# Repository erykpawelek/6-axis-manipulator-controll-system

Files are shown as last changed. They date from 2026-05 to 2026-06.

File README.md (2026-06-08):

# Robot for Car Windshield Assembly

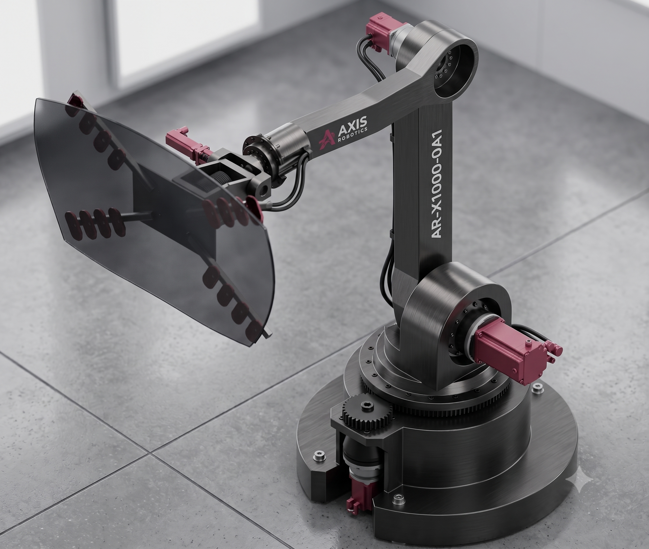
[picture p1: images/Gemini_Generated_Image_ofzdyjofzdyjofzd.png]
Visualization


**Authors:** Eryk Pawełek, Dawid Pietrzyk, Nikodem Weltrowski, Maksymilian Wywiał

## Project Overview

This project details the design, kinematic and dynamic analysis, and control simulation of a 6-Degree of Freedom (DoF) articulated mechatronic manipulator dedicated to the automated assembly of automotive windshields integrated and simulatied fully in MATLAB/Simulink environment using Simscape addition. The system is engineered to handle variable payload capacities (up to approximately 20 kg for the glass alone, plus the mass of a multi-pad vacuum gripping system) while maintaining the high spatial precision required for continuous urethane adhesive application and frame insertion.

A fully articulated structure utilizing 6 rotational joints driven by AC servomotors was selected to maximize maneuverability and minimize the spatial footprint, allowing the end-effector to reach complex car body angles without collision.

## Design Assumptions & Motion Parameters

To ensure safe handling of fragile laminated glass and high positioning accuracy, the motion parameters were bounded below the absolute maximum capabilities of standard industrial robots. The operation is divided into two distinct phases:

- **Transfer Phase:** Fast transit from the picking station to the vehicle workspace. Maximum Tool Center Point (TCP) velocity is set to $1.0m/s$ with an acceleration of $2.0m/s^{2}$.
- **Mounting Phase:** Precision alignment and insertion. Maximum TCP velocity is reduced to $0.25m/s$ with an acceleration of $0.5m/s^{2}$

## Kinematic Analysis

### Denavit-Hartenberg Parameters

The spatial geometry of the manipulator is defined using the standard Denavit-Hartenberg (DH) convention.

| $i$ | $\theta_{i}$ | $d_{i}$ | $a_{i}$ | $\alpha_{i}$ | $Range of Motion$ |
| :-: | :---: | :-----: | :-----: | :---: | :---: |
|  1  | $\theta_{1}$ | $d_{1}$ | $0$ | $-\frac{\pi}{2}$ | $\pm180^{\circ}$ |
|  2  | $\theta_{2}-\frac{\pi}{2}$ | $0$ | $a_{2}$ | $0$ | $\pm60^{\circ}$ |
|  3  | $\theta_{3}$ | $0$ | $0$ | $-\frac{\pi}{2}$ | $+60^{\circ} / -240^{\circ}$ |
|  4  | $\theta_{4}$ | $d_{4}$ | $0$ | $\frac{\pi}{2}$  | $\pm180^{\circ}$ |
|  5  | $\theta_{5}$ | $0$ | $0$ | $-\frac{\pi}{2}$ | $\pm90^{\circ}$ |
|  6  | $\theta_{6}$ | $d_{6}$ | $0$ | $0$ | $\pm180^{\circ}$ |

> (Note: $d_{1}=200mm$, $a_{2}=1300mm$, $d_{4}=1200mm$, $d_{6}=400mm$)

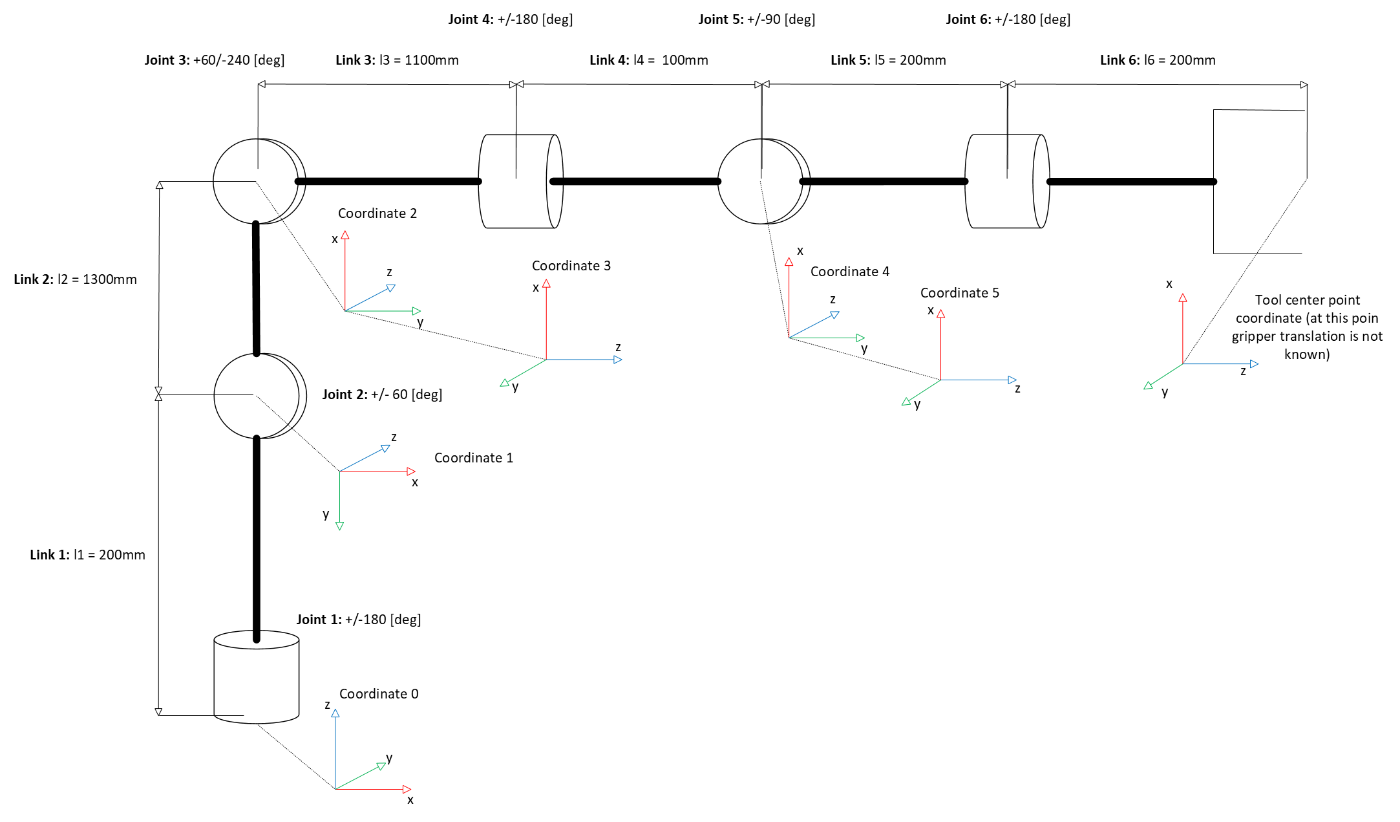
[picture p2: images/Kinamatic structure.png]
Kinematic structure


## Inverse kinematics

The inverse kinematics problem was solved analytically using the kinematic decoupling method, which is applicable because the three consecutive wrist axes (J4, J5, J6) intersect at a single mathematical point.

The position of the wrist center $\overline{P_{a}}$ is isolated from the Tool Center Point (TCP) $\overline{P}$ and the end-effector translation $\overline{P_{w}}$:

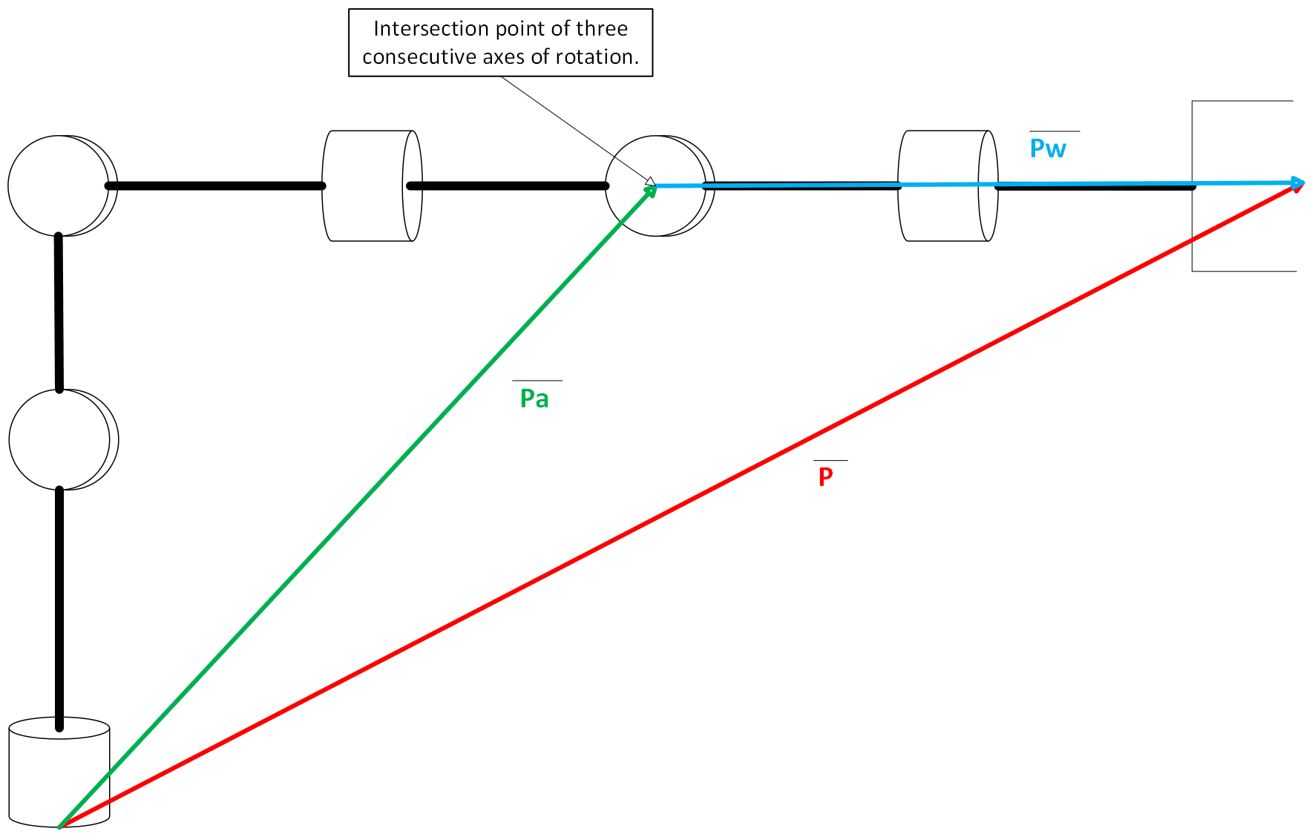
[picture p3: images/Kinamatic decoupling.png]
Kinematic decoupling


## $$\overline{P_{a}} = \overline{P} - \overline{P_{w}}$$

Solving for the base and arm joints ($\theta_{1}$, $\theta_{2}$, $\theta_{3}$), the base rotation is derived as:

### Joint 1 ($\theta_1$):

**$\theta_{1}=atan2(-P_{ay},-P_{ax})$**

or

**$\theta_{1}=atan2(P_{ay},P_{ax})$**

### Joint 3 ($\theta_3$):

First, the intermediate variable $D$ is calculated:

**$D=\frac{a_{2}^{2}+d_{4}^{2}-(P_{ax}^{2}+P_{ay}^{2})-(P_{az}-d_{1})^{2}}{2\cdot a_{2}\cdot d_{4}}$**

Then, $\theta_3$ is extracted using the $atan2$ function:

**$\theta_{3}=atan2(D,\pm\sqrt{1-D^{2}})$**

### Joint 2 ($\theta_2$):

Using the calculated $\theta_3$, constants $M$ and $N$ are defined:

**$M=a_{2}-d_{4}\cdot sin(\theta_{3})$**

**$N=d_{4}\cdot cos(\theta_{3})$**

The solution for $\theta_2$ is:

**$\theta_{2}=atan2(M\cdot R-N\cdot(P_{ax}-d_{1}),N\cdot R+M\cdot(P_{ax}-d_{1}))$**

### Joint 5 ($\theta_5$):

**$\theta_{5}=atan2(\pm\sqrt{R_{13}^{2}+R_{23}^{2}},R_{33})$**

### Joint 4 ($\theta_4$):

The solution depends on the variant of the $sin(\theta_5)$ solution.

For $sin(\theta_5)>0$:

**$\theta_{4}=atan2(-R_{23},-R_{13})$**

For $sin(\theta_5)<0$:

$\theta_{4}=atan2(R_{23},R_{13})$

### Joint 6 ($\theta_6$):

The solution follows the logic for the chosen root of $\theta_5$.

For the positive root of $\theta_5$:

$\theta_{6}=atan2(-R_{32},R_{31})$

For the negative root of $\theta_5$:

$\theta_{6}=atan2(R_{32},-R_{31})$

## Singularity Analysis

Four primary kinematic singularities were identified and mapped within the workspace:

1. **Shoulder Singularity:** Occurs when the wrist center lies exactly on the vertical $z_{0}$ axis ($P_{ax}=0, P_{ay}=0$), resulting in infinite solutions for $\theta_{1}$.

2. **Workspace Boundary:** Occurs when the target exceeds the maximum reach, yielding imaginary roots for $\theta_{3}$.

3. **Elbow Singularity:** Arises when the arm is fully extended or folded ($\theta_{3} = \pm90^{\circ}$), demanding infinite joint velocity for radial extension.

4. **Wrist Singularity:** Occurs when joint 5 is at $0^{\circ}$ or $\pm180^{\circ}$, causing axes 4 and 6 to become coaxial, making their individual angles indeterminate.

## Dynamic Analysis

A dynamic model was developed to calculate the joint torques required for trajectory execution. While the Euler-Lagrange method was initially explored, the analytical derivatives for the rotational kinetic energy of the distal links proved computationally expensive.

The equations of motion are expressed in standard matrix form:

$$\tau = M\dot{q} + C + G$$

> Where $M$ is the inertia matrix, $C$ represents the Coriolis and centrifugal forces, $G$ is the gravity vector, and $\dot{q}$ contains the joint accelerations.

## Simulation & Control (Simscape Multibody)

The CAD geometry, including proper mass and inertia tensors (calculated for steel, $\rho = 7850~kg/m^{3}$), was integrated into MATLAB/Simulink using the Simscape Multibody module.

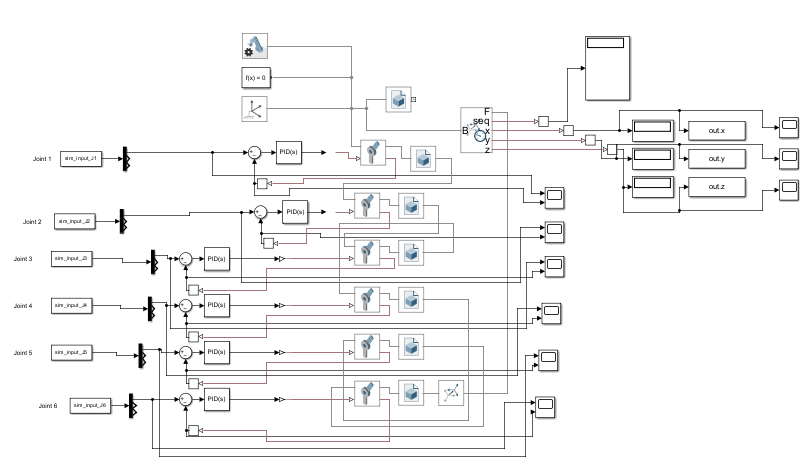
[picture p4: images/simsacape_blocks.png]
Simsacape block diagram


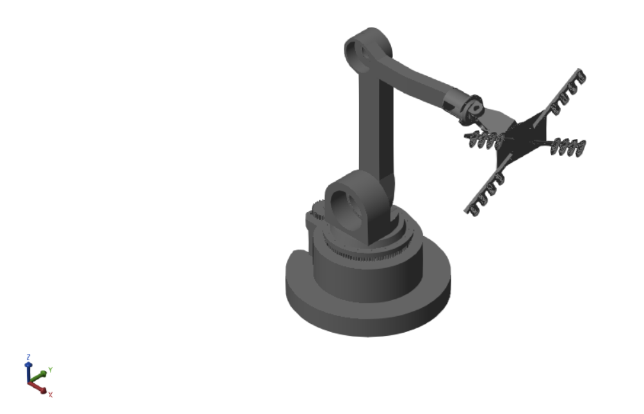
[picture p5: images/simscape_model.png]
Simsacape model


## Trajectory Generation

A 5th-order polynomial interpolation was applied for joint space trajectories to ensure smooth, continuous velocity and acceleration profiles, while trapezoidal generation was utilized for linear motion segments.

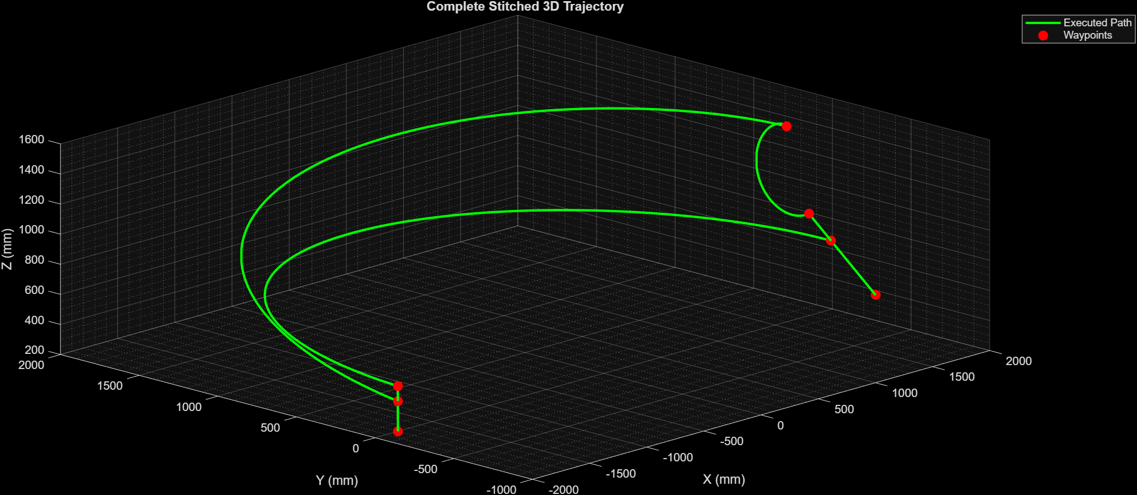
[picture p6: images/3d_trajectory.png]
3D path

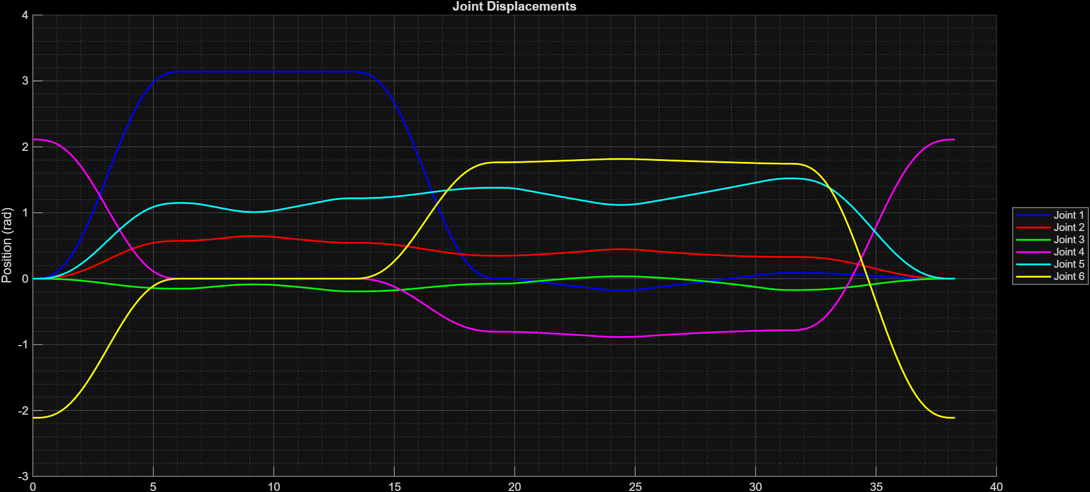
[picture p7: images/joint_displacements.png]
j_dis

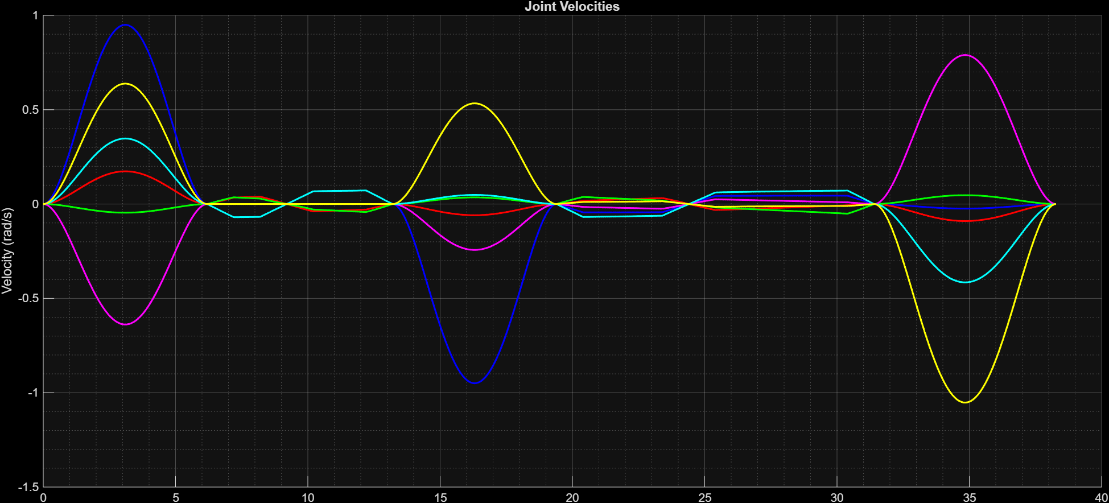
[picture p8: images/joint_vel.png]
j_vel

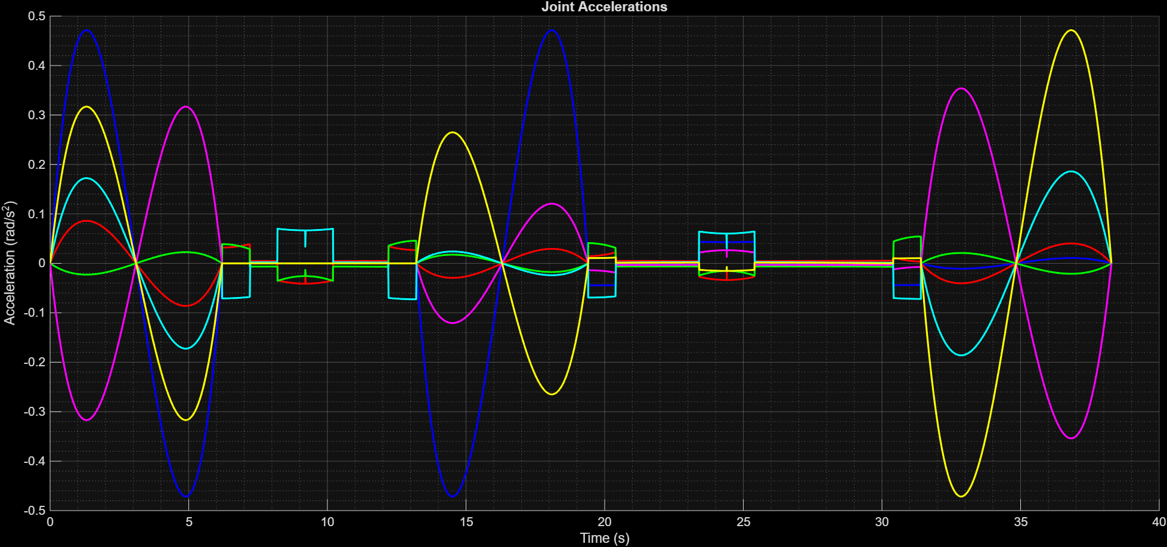
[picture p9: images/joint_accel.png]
j_accel


## PID Control and Error Evaluation

Independent PID controllers were tuned for each joint using a decoupled approach, targeting a settling time of $<0.5s$ and overshoot of $<10\%$.

Tracking evaluation revealed high precision in the joint space (maximum deviations of $\pm0.035rad$ on Joint 1). However, error amplification through the extended kinematic chain (up to $1300mm$ link lengths) resulted in measurable Cartesian deviations at the end-effector.

- X-axis error: Peaked at $\pm44~mm$ during high-speed sweeps.
- Y-axis error: Peaked at $89~mm$ during major joint-space transitions.
- Z-axis error: Oscillated between $5mm$ and $30mm$ during motion.

Analysis indicated that static residual errors at the proximal joints are heavily influenced by the sampling time ($0.001s$), which limits the aggressiveness of the derivative gain before inducing system instability (derivative kick).

## Assembly drawing

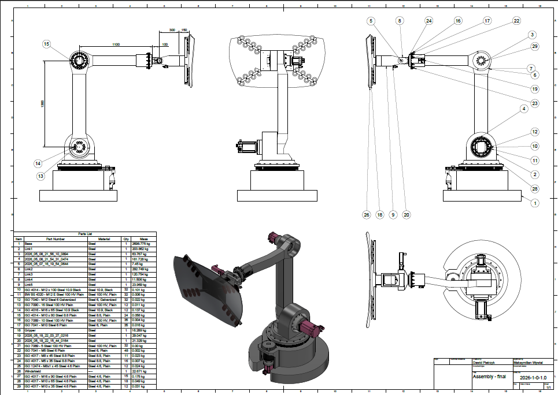
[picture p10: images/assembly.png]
assembly


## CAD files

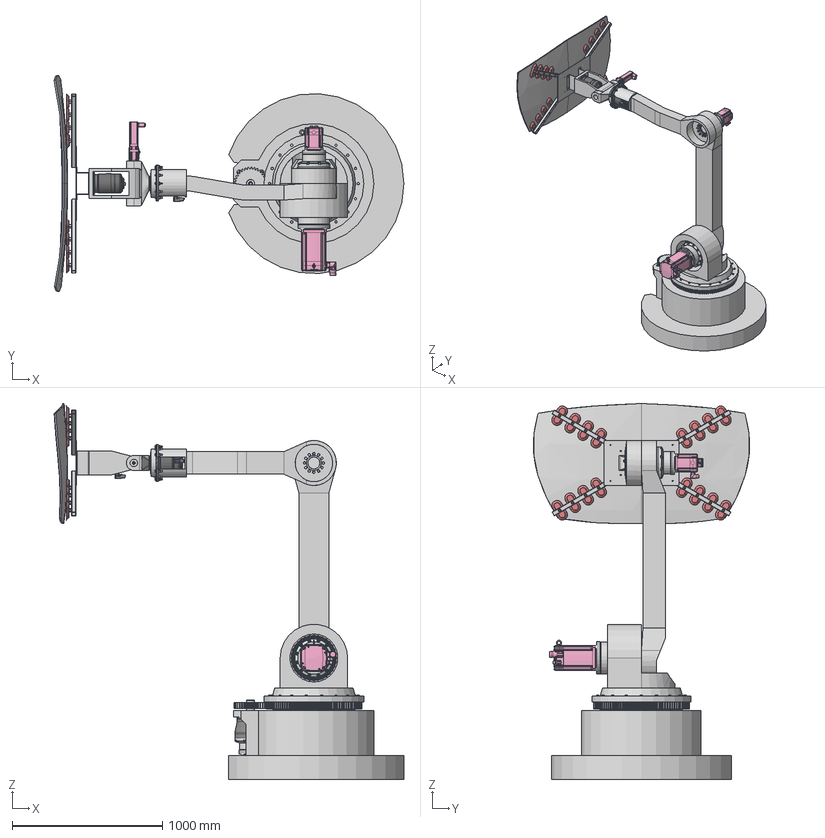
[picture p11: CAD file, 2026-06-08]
simulink/CAD/final/Assembly - final-stp.step
2331.7 x 1441.1 x 2506.2 mm
BALL .750 inch.step_10 x 74
BALL .750 inch.step
BALL .750 inch.step_1
BALL .750 inch.step_2
BALL .750 inch.step_3
BALL .750 inch.step_4
BALL .750 inch.step_5
BALL .750 inch.step_6
BALL .750 inch.step_7
BALL .750 inch.step_8
BALL .750 inch.step_9
HS6-021E002 ASSY.step
HS6-021E003 ASSY.step
HS6021 UPPER SEAL (25382003).step
HS6-021 LOWER SEAL (25382004).step
20069000_20069040.step
Taper Pin_04_1.50.step
ALEMITE 1644-B.step x 2
spinning table
Spur Gear 33 teeth
link1
link2
link4
link5
ISO 4014 - M12 x 100 Steel 10.9 Black x 32
BW BS 4320 - M12 E Steel 100 HV Plain x 32
ISO 7040 - M12 Steel 6 Galvanized x 32
ISO 7090 - 16 Steel 100 HV Plain
ISO 7090 - 16 Steel 100 HV Plain_1
ISO 7090 - 16 Steel 100 HV Plain_2
ISO 7090 - 16 Steel 100 HV Plain_3
ISO 7090 - 16 Steel 100 HV Plain_4
ISO 7090 - 16 Steel 100 HV Plain_5
ISO 7090 - 16 Steel 100 HV Plain_6
ISO 7090 - 16 Steel 100 HV Plain_7
ISO 7090 - 16 Steel 100 HV Plain_8
ISO 7090 - 16 Steel 100 HV Plain_9
ISO 7090 - 16 Steel 100 HV Plain_10
ISO 7090 - 16 Steel 100 HV Plain_11
ISO 4016 - M16 x 65 Steel 10.9 Black
ISO 4016 - M16 x 65 Steel 10.9 Black_1
ISO 4016 - M16 x 65 Steel 10.9 Black_2
ISO 4016 - M16 x 65 Steel 10.9 Black_3
ISO 4016 - M16 x 65 Steel 10.9 Black_4
ISO 4016 - M16 x 65 Steel 10.9 Black_5
ISO 4016 - M16 x 65 Steel 10.9 Black_6
ISO 4016 - M16 x 65 Steel 10.9 Black_7
ISO 4016 - M16 x 65 Steel 10.9 Black_8
ISO 4016 - M16 x 65 Steel 10.9 Black_9
ISO 4016 - M16 x 65 Steel 10.9 Black_10
ISO 4016 - M16 x 65 Steel 10.9 Black_11
ISO 4014 - M10 x 80 Steel 8.8 Plain
ISO 4014 - M10 x 80 Steel 8.8 Plain_1
ISO 4014 - M10 x 80 Steel 8.8 Plain_2
ISO 4014 - M10 x 80 Steel 8.8 Plain_3
ISO 4014 - M10 x 80 Steel 8.8 Plain_4
ISO 4014 - M10 x 80 Steel 8.8 Plain_5
ISO 4014 - M10 x 80 Steel 8.8 Plain_6
ISO 4014 - M10 x 80 Steel 8.8 Plain_7
ISO 4014 - M10 x 80 Steel 8.8 Plain_8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

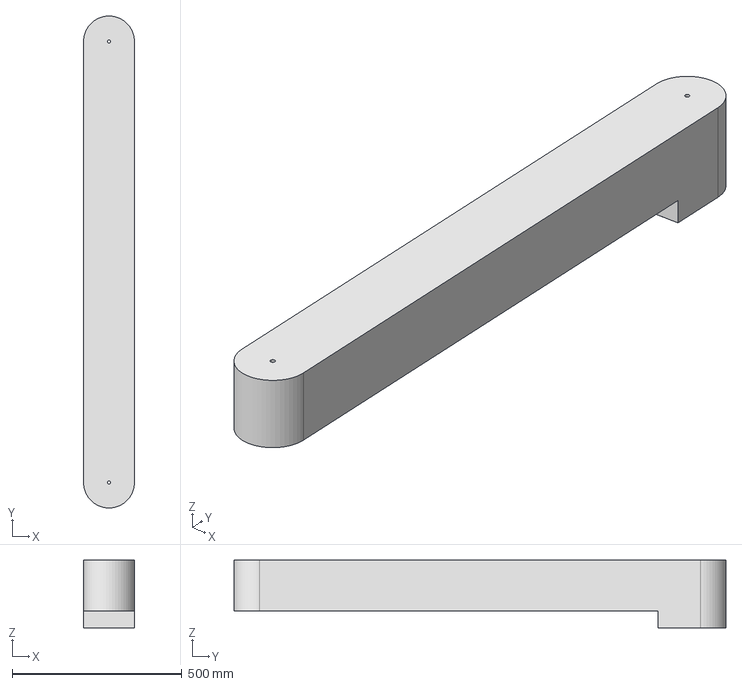
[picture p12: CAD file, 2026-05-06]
simulink/CAD/simplified/step/link2_fixed.stp
150.0 x 1450.0 x 200.0 mm

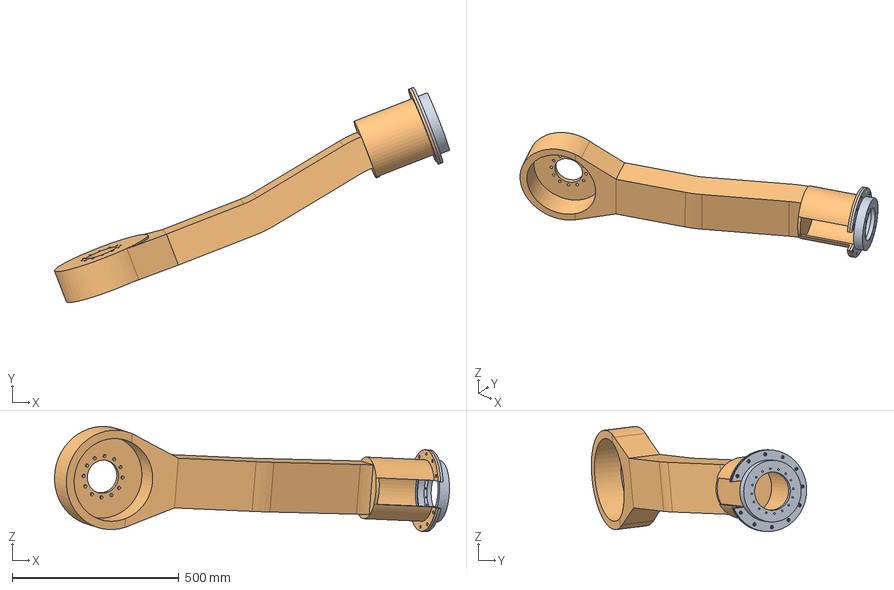
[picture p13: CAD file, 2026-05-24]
simulink/CAD/final/link3-v14.step
1183.7 x 645.2 x 315.1 mm

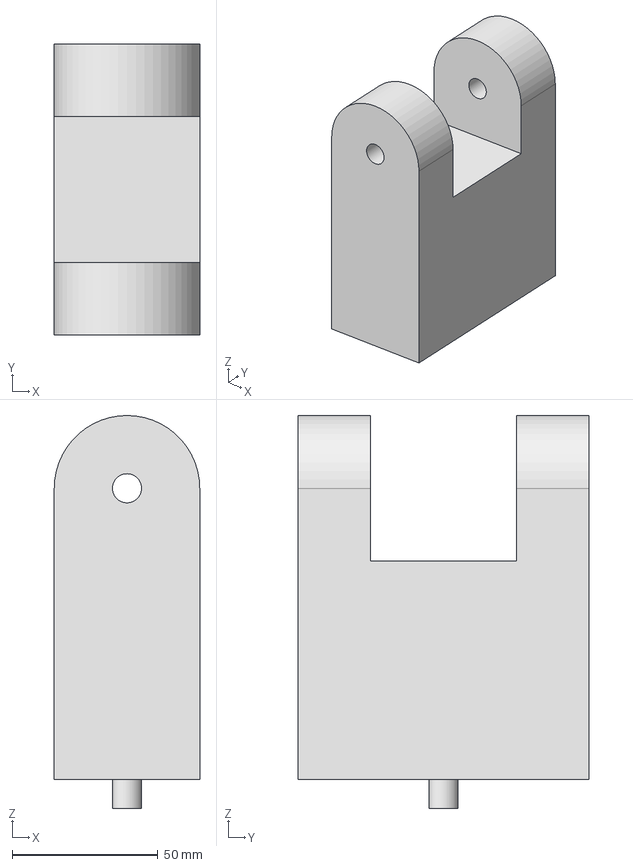
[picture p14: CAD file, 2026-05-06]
simulink/CAD/simplified/step/link4.stp
50.0 x 100.0 x 135.0 mm

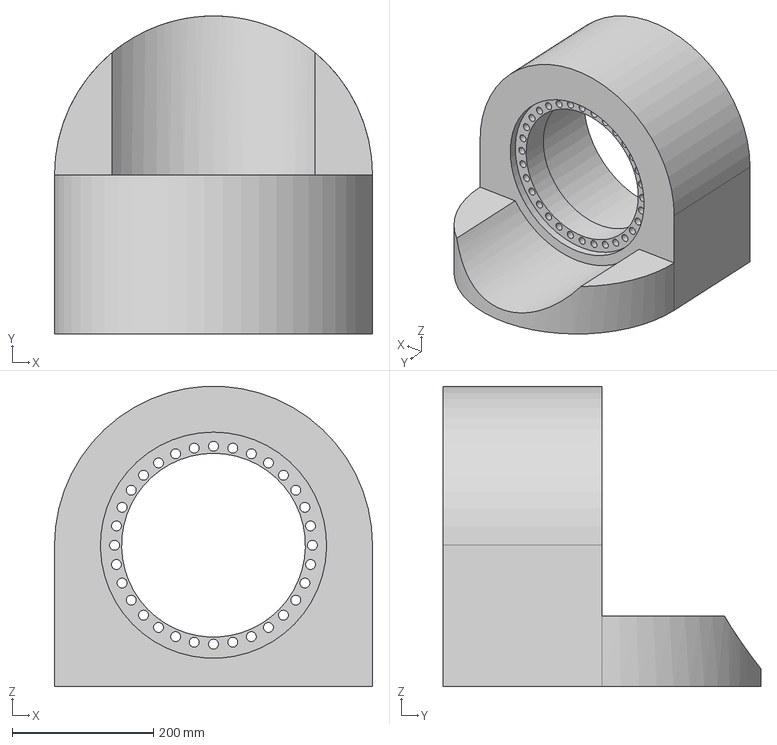
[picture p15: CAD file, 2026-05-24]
simulink/CAD/final/link1-v7.step
450.0 x 450.0 x 424.6 mm

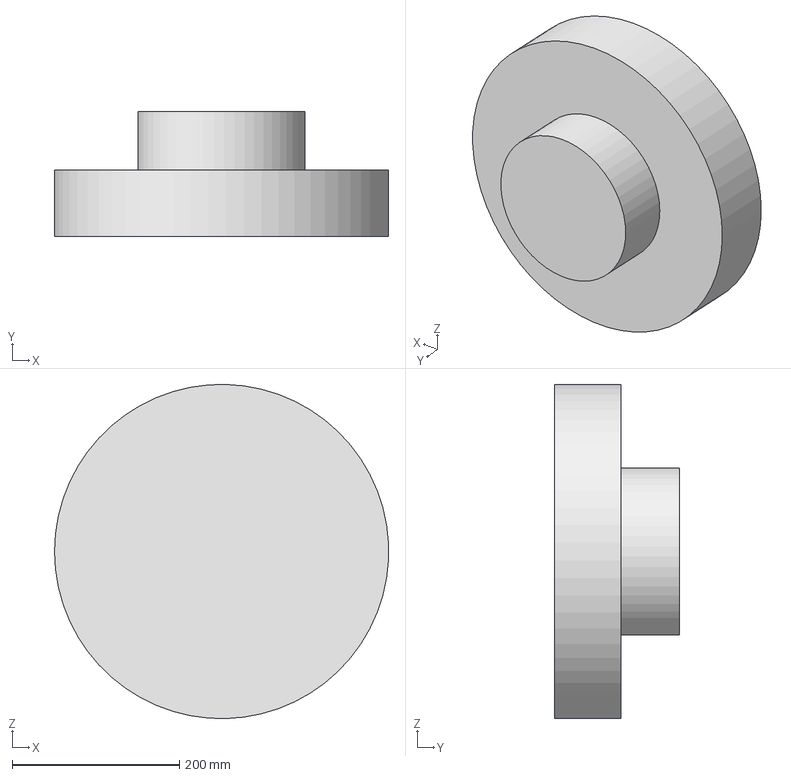
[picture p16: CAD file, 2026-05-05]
simulink/CAD/simplified/step/base.stp
399.7 x 150.0 x 399.9 mm

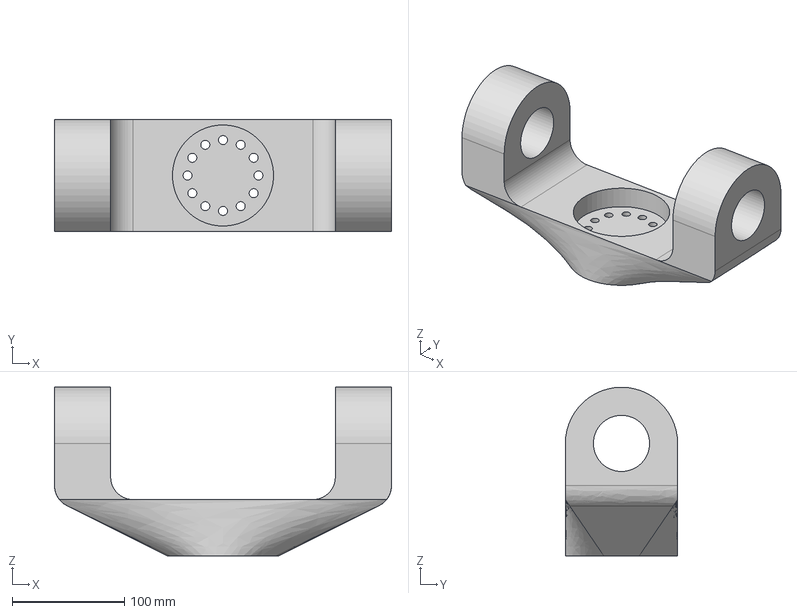
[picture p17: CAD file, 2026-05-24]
simulink/CAD/final/link4-v3.step
300.0 x 100.0 x 150.0 mm

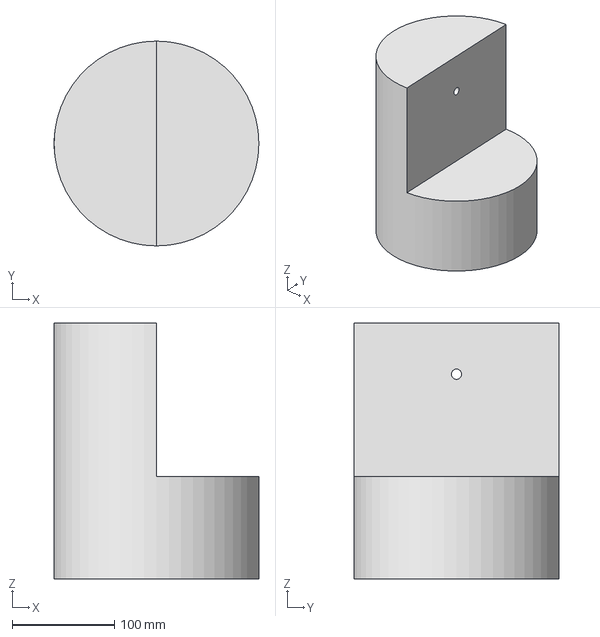
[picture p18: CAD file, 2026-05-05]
simulink/CAD/simplified/step/link1.stp
200.0 x 200.0 x 250.0 mm

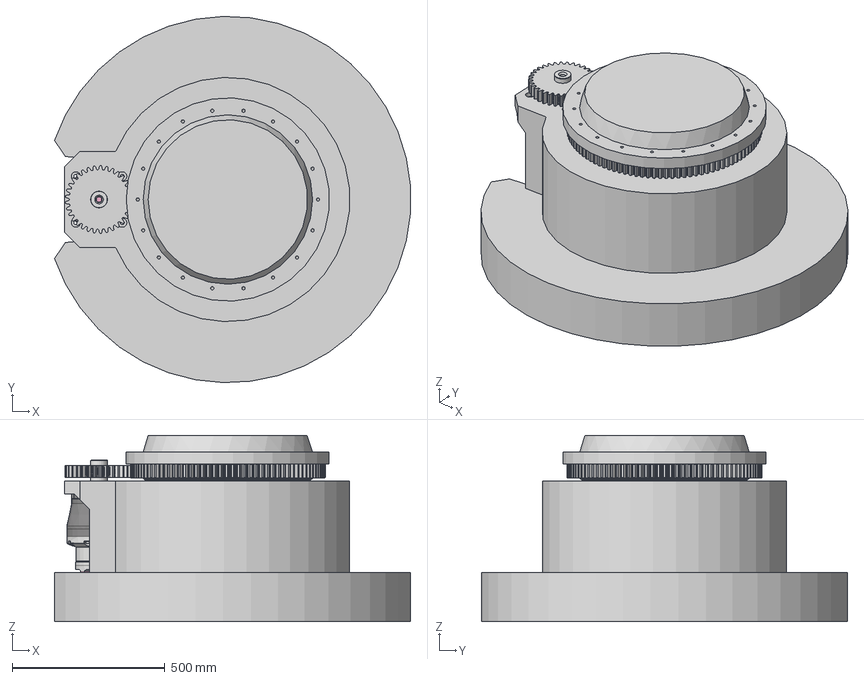
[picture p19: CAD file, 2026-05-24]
simulink/CAD/final/base-v7.step
1166.2 x 1199.6 x 609.9 mm
BALL .750 inch.step_10 x 74
BALL .750 inch.step
BALL .750 inch.step_1
BALL .750 inch.step_2
BALL .750 inch.step_3
BALL .750 inch.step_4
BALL .750 inch.step_5
BALL .750 inch.step_6
BALL .750 inch.step_7
BALL .750 inch.step_8
BALL .750 inch.step_9
HS6-021E002 ASSY.step
HS6-021E003 ASSY.step
HS6021 UPPER SEAL (25382003).step
HS6-021 LOWER SEAL (25382004).step
20069000_20069040.step
Taper Pin_04_1.50.step
ALEMITE 1644-B.step x 2
spinning table
Spur Gear 33 teeth

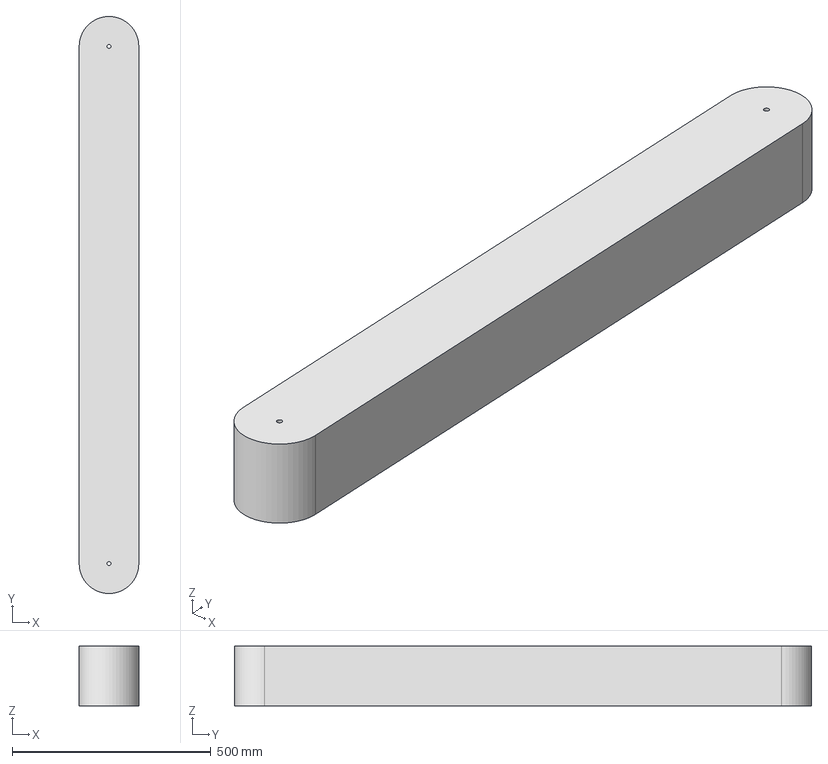
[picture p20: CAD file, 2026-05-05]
simulink/CAD/simplified/step/link2.stp
150.0 x 1450.0 x 150.0 mm

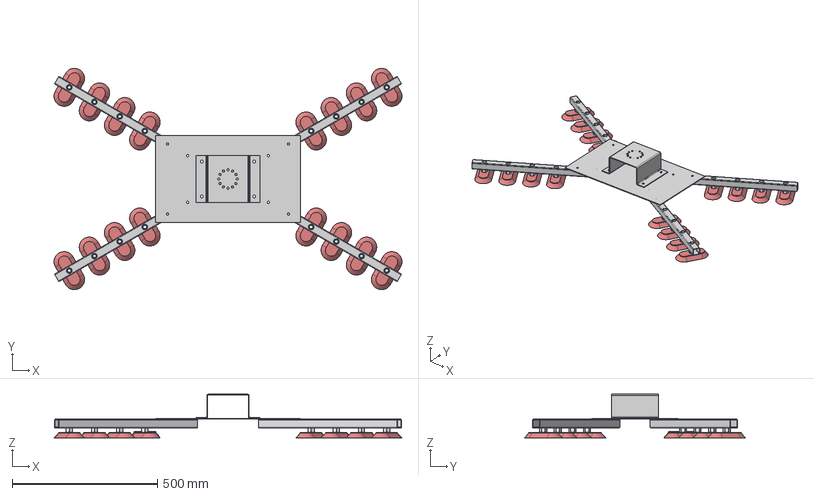
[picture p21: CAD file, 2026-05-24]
simulink/CAD/final/Gripper-v10.step
1196.1 x 760.6 x 150.0 mm
square profile x 4
blaszka glowna
Elliptical flat vacuum cups - High Grip VVD-70-140-G3/8-B x 16
gripper mount

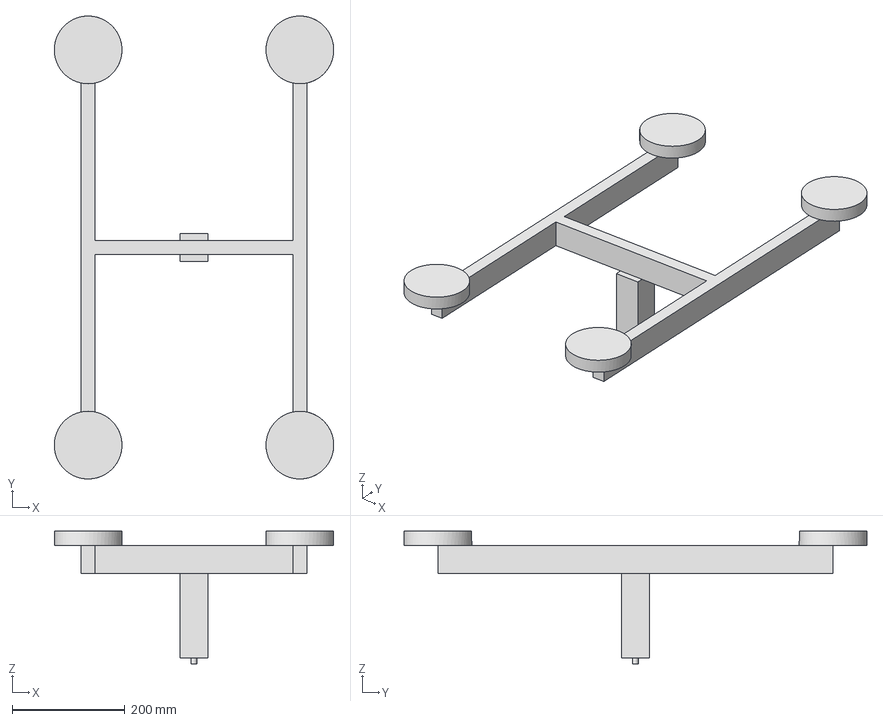
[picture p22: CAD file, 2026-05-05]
simulink/CAD/simplified/step/link6.stp
495.0 x 820.0 x 235.0 mm

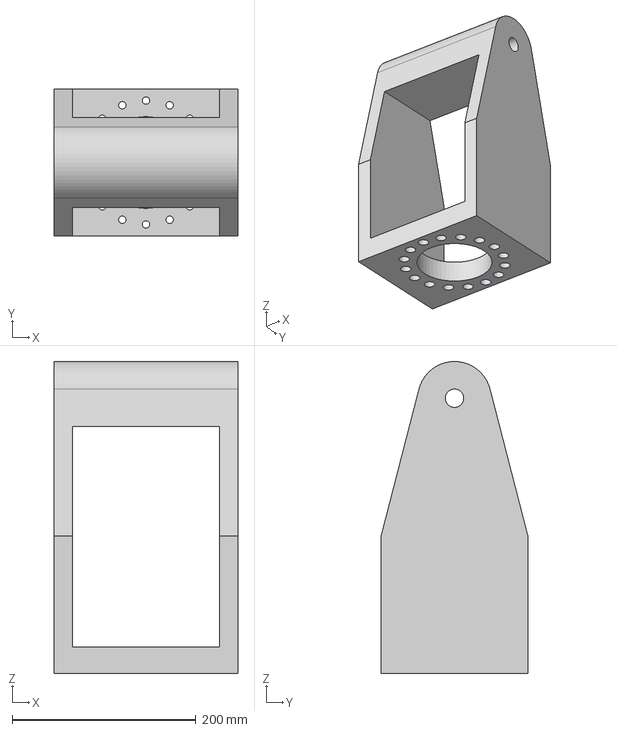
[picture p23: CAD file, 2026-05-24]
simulink/CAD/final/link5-v6.step
200.0 x 160.0 x 340.0 mm

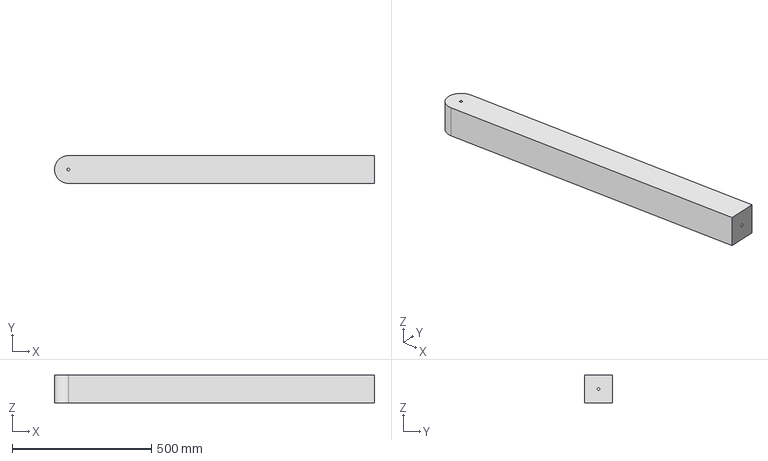
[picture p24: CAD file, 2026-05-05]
simulink/CAD/simplified/step/link3.stp
1150.0 x 100.0 x 100.0 mm

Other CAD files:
simulink/CAD/final/link2-v6.step
simulink/CAD/simplified/step/link5.stp
simulink/CAD/final/windshield-v2.step
simulink/CAD/simplified/OldVersions/link6.0003.ipt
simulink/CAD/simplified/base.ipt
simulink/CAD/simplified/link1.ipt
simulink/CAD/simplified/link2.ipt
simulink/CAD/simplified/link3.ipt
simulink/CAD/simplified/link4.ipt
simulink/CAD/simplified/link5.ipt
simulink/CAD/simplified/link6.ipt

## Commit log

2026-03-23 Initial commit, calculation of forward kinematics
2026-03-27 Refactor, Inverse kinematics of 3 first joints added, post procesing of calculated solutions added
2026-03-28 code refactor, function names claryfied, inverse kinematics module in progress
2026-03-28 Inverse kinematics validation module finished
2026-03-29 Inverse and Forward kinematics functions implemented
2026-05-05 Trajectory solver in development. Simscape simplified model without kinematic solver added
    [base.ipt, base.stp, link1.ipt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]
2026-05-06 SimScape simplifiad model debbuged. Trajectory generator rev_1
    [link2_fixed.stp, link4.stp]
2026-05-17 Joint trajectory solver added along with Linear trajectory solver, Implemented one whole program
2026-05-20 Simscape pid model added
2026-05-24 Final cad simscape implementation in progress
    [Gripper-v10.step, base-v7.step, link1-v7.step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]
2026-06-08 Readme and documentation polished
    [Assembly - final-stp.step]
